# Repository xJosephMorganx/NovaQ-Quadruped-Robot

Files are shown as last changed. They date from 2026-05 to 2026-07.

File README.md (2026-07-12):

# NovaQ Quadruped Robot with Computer Vision

This repository documents and contains the files for a real quadruped robot built around an Arduino UNO Q. The project combines mechanical design, 3D printed parts, embedded motion control, a Python control layer, a web-based operator interface, and computer vision routines using OpenCV and Edge Impulse.

The robot has four legs with two degrees of freedom per leg. Eight MG996R servomotors are driven by a PCA9685 PWM controller, while the Arduino UNO Q separates high-level processing on its Linux side from low-level servo execution on its microcontroller side.

## Overview

The goal of the project is to build a functional robotics platform that can walk, turn, return to calibrated poses, show a greeting motion, stream camera video, track a blue ball, and respond to hand gestures.

```text
Web UI / ROG Ally
  -> Arduino App Lab on UNO Q Linux
  -> Python application
  -> Arduino Bridge
  -> UNO Q microcontroller sketch
  -> PCA9685 over I2C
  -> 8x MG996R servomotors
```

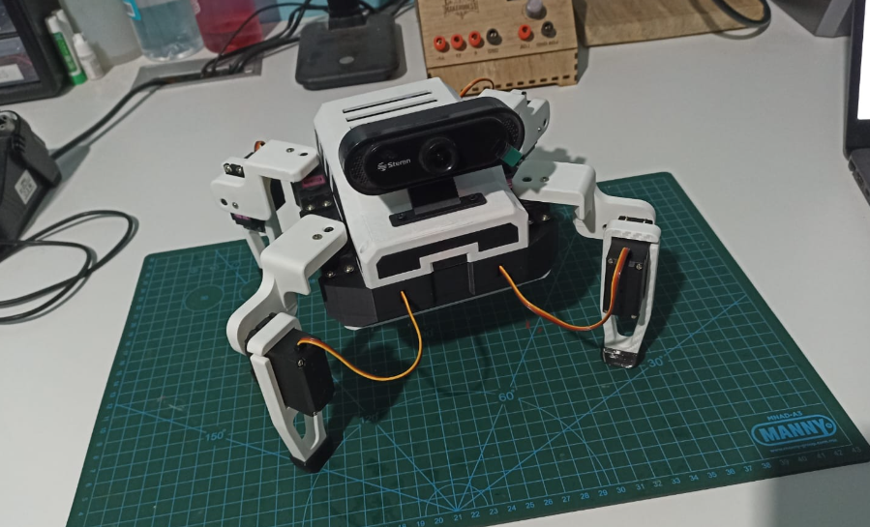
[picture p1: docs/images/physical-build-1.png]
Built quadruped robot


## Features

- Eight-servo quadruped platform with two degrees of freedom per leg.
- Manual Wi-Fi control through a browser-based web app.
- Live USB camera feedback for remote operation.
- OpenCV blue ball tracking mode.
- Edge Impulse hand gesture control mode.
- Motion routines for initial pose, stand, forward, backward, turns, and greeting.
- Smooth servo transitions using calibrated PCA9685 pulse values.
- 3D printed mechanical structure with printable STL files included in the repository.
- Separate power paths for logic and actuator stages.

## Mechanical Design

The mechanical structure was designed in Fusion 360 using the real dimensions of the main components: Arduino UNO Q, PCA9685 module, servomotors, battery, power bank, USB hub, camera, and internal wiring space. The design uses a central body, top case, base cover, camera mount, shoulders, legs, and feet.

Rigid parts were fabricated mainly in PLA. The feet were printed in TPU to improve floor contact and reduce slipping during gait tests. The repository includes STL files under `Design/STL/`, ready to slice and print.

The full mechanical design is also included for download and modification:

- `Design/Nova-Q.f3z`: editable Fusion 360 archive.
- `Design/Nova-Q.step`: neutral CAD export for other CAD tools.

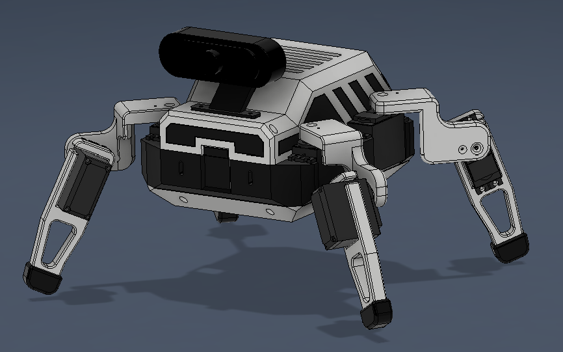
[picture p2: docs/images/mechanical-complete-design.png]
completed robot assembly in Fusion 360


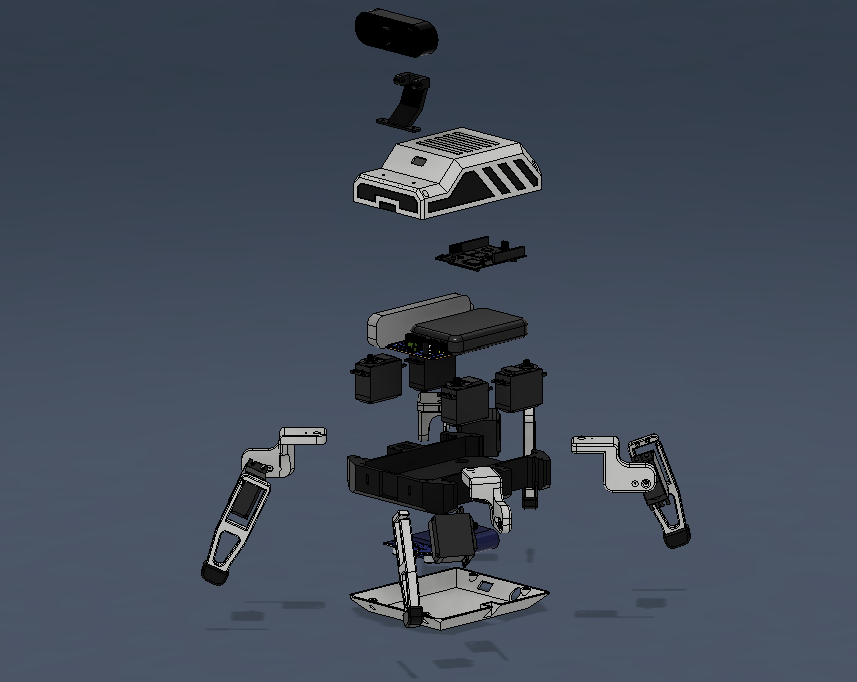
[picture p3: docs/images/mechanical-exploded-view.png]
Exploded robot assembly in Fusion 360


## Electrical and Electronic Design

The robot uses an Arduino UNO Q as the main controller and a PCA9685 module to generate PWM signals for the eight MG996R servomotors. The PCA9685 communicates with the UNO Q through I2C and drives channels `0-7`.

The power design separates logic and actuator supply. The servo stage is powered from a 12 V Li-ion battery through a buck converter adjusted for the MG996R operating voltage. The logic/peripheral stage uses a 5 V power bank. A common ground must be shared between the UNO Q, PCA9685, and servo power supply.

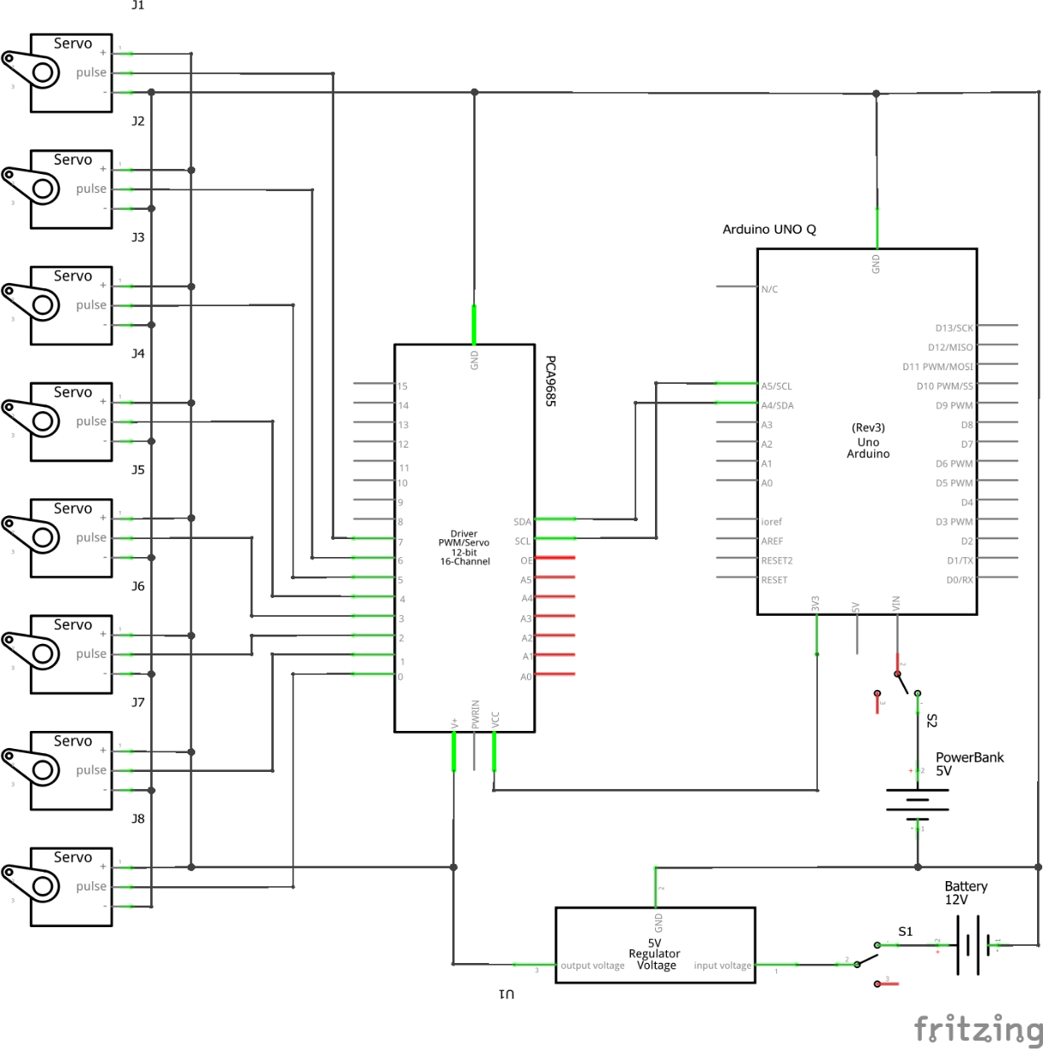
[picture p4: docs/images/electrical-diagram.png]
Electrical/electronic diagram


Important electrical notes:

- Do not power the MG996R servos directly from the UNO Q.
- Verify buck converter output before connecting the servos.
- Keep grounds common across control and power stages.
- Use wiring sized appropriately for the current demanded by the servos.
- Keep a physical power switch or battery disconnect available during testing.

## Bill of Materials

| Component | Type | Operating Voltage | Signal / Control | Purpose |
| --- | --- | --- | --- | --- |
| 8x MG996R servomotors | Actuator | 4.8-7.2 V | PWM | High-torque joints for legs |
| PCA9685 module | PWM controller | 3.3-5 V logic | I2C | 16-channel, 12-bit PWM generation |
| 12 V Li-ion battery | Power source | 12 V | Power | Main actuator supply |
| Buck converter | Regulator | 12 V input / adjustable output | DC-DC | Servo voltage regulation |
| ON/OFF switch | Switch | According to supply | Mechanical switching | Main power control |
| 5 V power bank | Auxiliary power source | 5 V | USB | Logic and peripheral supply |
| Arduino UNO Q | Control board | 5 V input / 3.3 V logic | Digital / I2C / Bridge | Main control and processing unit |
| Anker USB-C hub | USB hub | 5 V / USB-C PD | USB | Camera and peripheral connection |
| Steren COM-122 webcam | Visual sensor | 5 V USB | USB video | Camera input for live view and vision modes |
| 3D printed PLA parts | Mechanical structure | N/A | N/A | Body, cover, shoulders, legs, and camera mount |
| TPU feet | Contact parts | N/A | N/A | Traction and floor contact |

## Software

The software is split into two layers:

- **Microcontroller layer**: the Arduino sketch receives motion commands and executes calibrated servo routines through the PCA9685.
- **Linux/Python layer**: the Python app serves the web interface, handles camera capture, runs OpenCV logic, receives Edge Impulse results, and sends high-level commands through Arduino Bridge.

The repository also includes a dedicated servo calibration web app in `Dev/Tools/uno-q-servo-calibrator`. This tool is used to test individual servos and adjust pulse values before running the full quadruped motion routines.

Main software tools and libraries:

- Arduino App Lab
- Arduino Bridge / RPC
- `Wire.h`
- `Adafruit_PWMServoDriver.h`
- Python
- OpenCV
- Edge Impulse
- HTML, CSS, and JavaScript

## Web App

The web app is the main operator interface. It provides manual movement controls, keyboard input, touch input, connection state, last executed action, camera feedback, and access to the OpenCV and Edge Impulse modes.

## Desktop
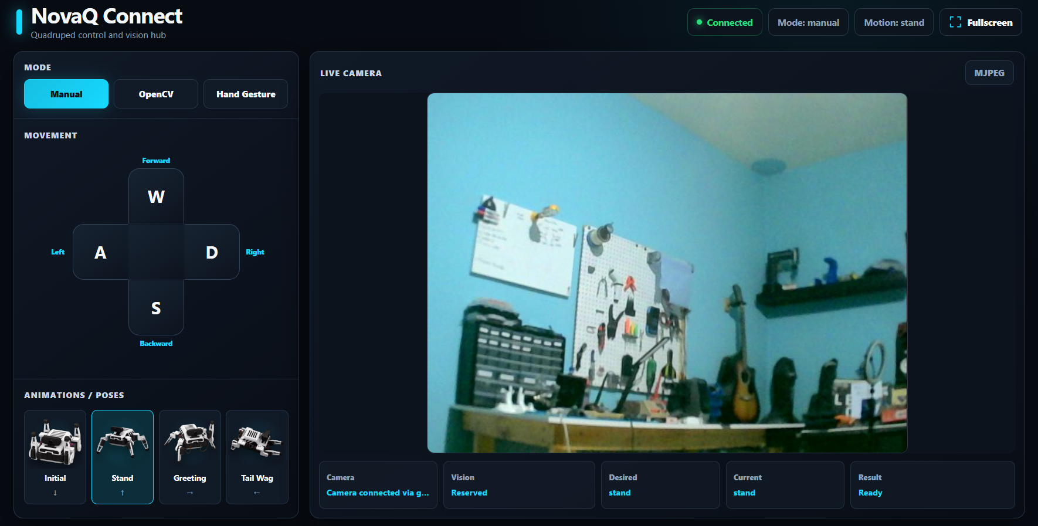
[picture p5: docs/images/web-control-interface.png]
Robot web control interface

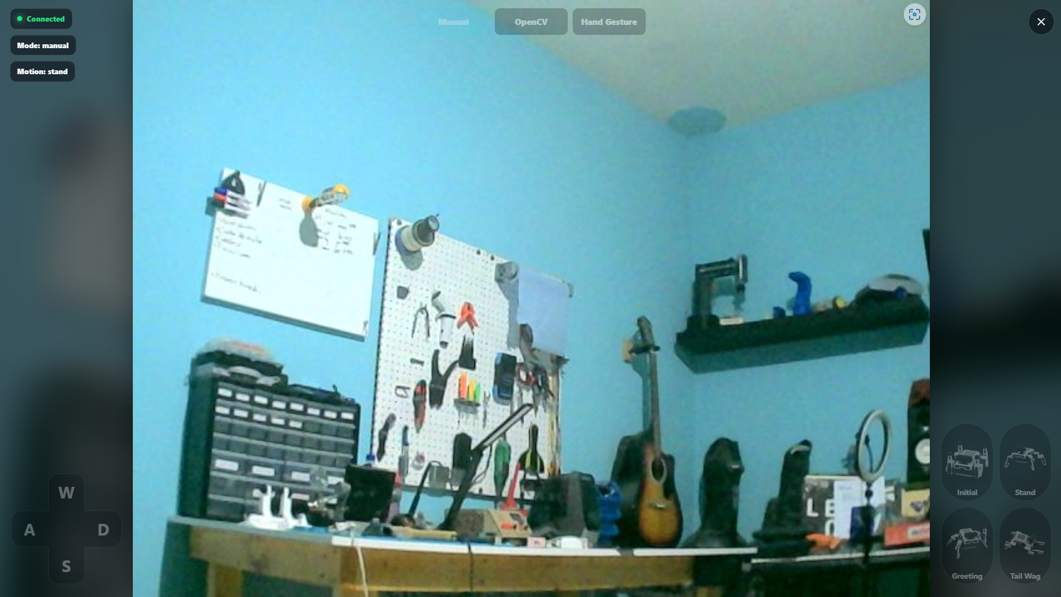
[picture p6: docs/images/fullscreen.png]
Robot web control interface fullscreen


## Mobile
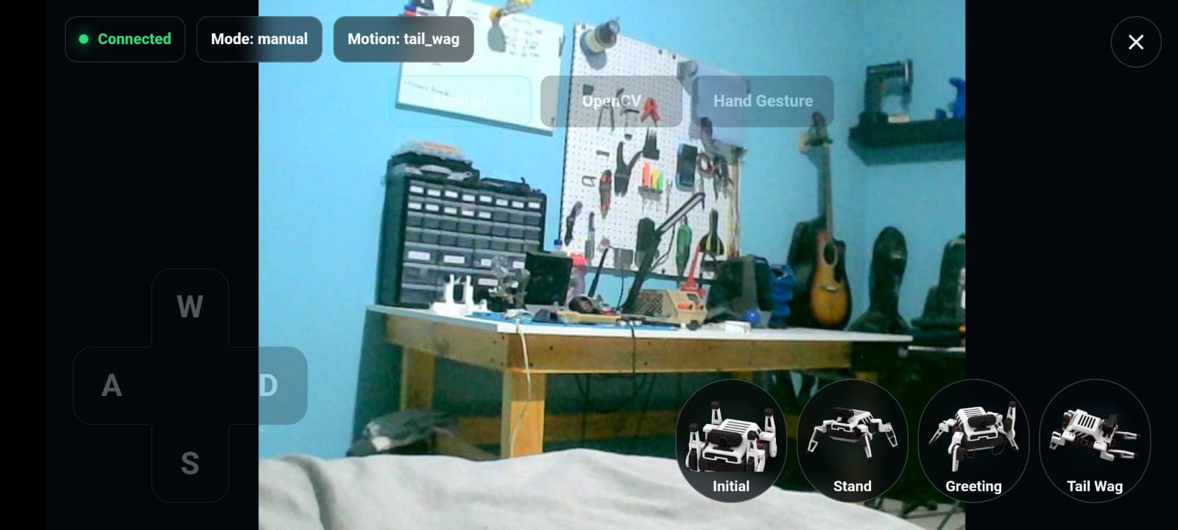
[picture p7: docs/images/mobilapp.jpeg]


Common controls:

| Input | Action |
| --- | --- |
| Arrow Down | Initial position |
| Arrow Up | Stand |
| W | Move forward |
| S | Move backward |
| A | Turn left |
| D | Turn right |
| Arrow Right | Greeting |
| Space | Manual mode |
| Page Down | OpenCV mode |
| F4 | Hand gesture mode |
| Escape | Focus/camera view |

## Computer Vision

The project includes two vision-based modes:

- **OpenCV mode**: detects a blue ball using color masking and shape filtering. The robot can search, correct its orientation, and move forward depending on the ball position.
- **Edge Impulse mode**: recognizes hand gestures and maps them to movement commands such as forward, backward, turn, stand, or greeting.

The camera is also used for live video feedback during manual operation.

## Installation

1. Clone the repository.

   ```bash
   git clone https://github.com/<user>/<repository>.git
   cd <repository>
   ```

2. Open the main Arduino App Lab project:

   ```text
   Dev/uno-q-control-station
   ```

3. Install or verify the sketch dependencies listed in:

   ```text
   Dev/uno-q-control-station/sketch/sketch.yaml
   ```

4. Install Python dependencies:

   ```bash
   pip install -r Dev/uno-q-control-station/python/requirements.txt
   ```

5. Calibrate the servos if needed using:

   ```text
   Dev/Tools/uno-q-servo-calibrator
   ```

6. Connect the UNO Q, PCA9685, servos, camera, power bank, battery, buck converter, and common ground.

7. Start the app from Arduino App Lab.

8. Open the control interface:

   ```text
   http://<UNO_Q_IP>:7000
   ```

## Usage

Before running gait routines, test the robot with the servo power disconnected and verify that the web app loads correctly. Then power the servos with the robot lifted off the table and test initial and stand positions first.

Recommended startup sequence:

1. Check wiring, polarity, and buck converter voltage.
2. Power the logic side and start the App Lab project.
3. Confirm the web app and camera feed work.
4. Connect servo power with the robot lifted.
5. Run `initial` and `stand`.
6. Test forward, backward, turn, and greeting routines.
7. Test OpenCV and Edge Impulse modes only after manual motion is stable.

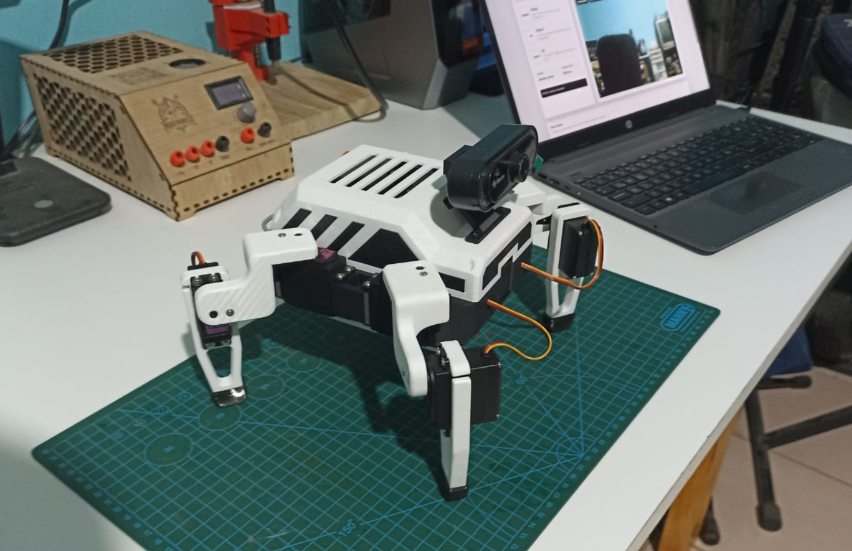
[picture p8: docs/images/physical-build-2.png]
Built quadruped robot alternate view


## Project Structure

```text
.
+-- Assets/
|   +-- Fusion_design.png
|   +-- NovaQ-schematic.png
|   +-- Physical1.png
|   +-- Physical2.png
|   +-- Nova_Q_exploded.mp4
+-- Design/
|   +-- Nova-Q.f3z
|   +-- Nova-Q.step
|   +-- STL/
|       +-- Base.stl
|       +-- Case.stl
|       +-- Camera_base.stl
|       +-- Leg*.stl
|       +-- Shoulder*.stl
|       +-- Foot*.stl
+-- Dev/
|   +-- uno-q-control-station/
|   |   +-- assets/
|   |   +-- python/
|   |   +-- sketch/
|   |   +-- app.yaml
|   +-- uno-q-keyboard-motion/
|   +-- Tools/
|       +-- uno-q-servo-calibrator/
+-- docs/
|   +-- images/
+-- README.md
```

## Notes

- The STL files in `Design/STL/` are included as printable mechanical parts. The editable Fusion 360 archive and STEP export are available in `Design/`.
- Servo pulse values depend on physical assembly and calibration. Recalibrate if servos, mounts, or linkages are changed.
- If additional external CAD files, trained models, or third-party assets are added later, their source and license should be documented in this README.
- The repository focuses on the complete robot implementation: electronics, firmware, Python software, web interface, mechanical integration, printable files, and documentation.

## License

This project is licensed under the GNU General Public License v3.0.

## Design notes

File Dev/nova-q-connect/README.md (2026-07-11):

# NovaQ Connect

Modern dark control and vision hub for the NovaQ quadruped. This app is an
independent UI-focused copy of `uno-q-control-station`; its Python bridge,
Arduino sketch, camera pipeline, vision modes, endpoints, motion sequencing,
and servo calibration remain unchanged.

## Controls

- Hold `W`, `S`, `A`, or `D` (keyboard or touch) to drive; release to return to
  `stand`.
- Arrow Down: `initial`
- Arrow Up: `stand`
- Arrow Right: `greeting`
- Arrow Left: `tail_wag`
- Space: `manual`
- PageDown: `opencv`
- F4: `hand_gesture`
- Escape: toggle Focus view

Focus view keeps the camera full-screen and presents low-opacity touch controls
for movement, poses, and app modes. Dashboard view shows only camera, vision,
desired motion, current motion, and the latest result.

## Services

- Web UI and API: port 7000
- Optional MJPEG stream: `http://<host>:7001/video-feed`
- API contracts are identical to `uno-q-control-station`.

Pose preview artwork is intentionally represented by CSS placeholders in the
first release and can later be replaced by pose-accurate photographic assets.

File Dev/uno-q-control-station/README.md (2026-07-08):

# UNO Q Control Station

Nueva app independiente para controlar el robot cuadrúpedo UNO Q sin reemplazar `uno-q-keyboard-motion`.

## Qué incluye

- Feed de cámara por snapshots en `/api/camera-frame`.
- Stream MJPEG en `http://<host>:7001/video-feed`.
- UI tipo focus view centrada en video con HUD.
- Modo Manual con teclado o controles tipo ROG Ally:
  - Arrow Down: `initial`
  - Arrow Up: `stand`
  - Arrow Right: `greeting`
  - W hold: `forward`
  - S hold: `backward`
  - A hold: `turn_left`
  - D hold: `turn_right`
  - Escape: focus/camera view
  - Space: `manual`
  - PageDown: `opencv`
  - F4: `hand_gesture`
- Modo OpenCV con tracking básico de pelota azul:
  - Máscara HSV azul.
  - Detector estricto por contorno circular: radio máximo, circularidad y densidad de relleno.
  - Si no detecta pelota: búsqueda con ráfaga de tres giros a la derecha.
  - Si detecta pelota fuera del centro: corrige con giro izquierdo/derecho.
  - Si detecta pelota centrada: avanza hacia adelante.
  - Si la pelota ya se ve grande/cerca: deja de mandar nuevos movimientos.
  - Entre movimientos espera 1.5 segundos sin mandar `stand`, para no revertir el avance o el giro recién hecho.
  - El feed muestra una vista anotada mientras OpenCV está activo.
- Modo Hand Gesture usando solo el brick `arduino:video_object_detection`:
  - Usa un modelo Edge Impulse en `/home/arduino/.arduino-bricks/ei-models/hand_gesture.eim`.
  - El brick detecta gestos de mano desnuda y entrega etiqueta, confianza y bounding box.
  - La app usa solo las cuatro etiquetas del modelo incluido:
    `five -> turn_right`, `good -> forward`, `neut -> backward`, `peace -> greeting`.
  - El mismo gesto se dispara una vez, con cooldown de 2.5 segundos, para evitar que un reconocimiento sostenido bloquee el control.
  - Las cajas anotadas expiran rapido para que el feed vuelva al video vivo si el brick deja de enviar detecciones.
  - Si no detecta mano o la etiqueta no esta mapeada: no manda movimiento.
  - La camara del brick usa `/dev/video0` directo y alimenta tambien el feed de la UI.
  - OpenCV queda reservado solo para el modo de pelota azul.
- Sketch con PCA9685 en `0x40`, canales `0-7`, `50 Hz`, reutilizando pulsos, poses y gait del prototipo.
  - `Shoulder_FR` calibrado en la app nueva con `initial=395`, `stand=330`; greeting usa `350` como soporte y fuerza retorno a `330`.

## Arquitectura de movimiento

La UI ya no encola un request por cada step mientras una tecla está presionada. Ahora publica cambios de estado con:

- `POST /api/mode` `{ "mode": "forward" }`
- `POST /api/mode` `{ "mode": "backward" }`
- `POST /api/mode` `{ "mode": "turn_left" }`
- `POST /api/mode` `{ "mode": "turn_right" }`
- `POST /api/mode` `{ "mode": "stand" }`
- `POST /api/mode` `{ "mode": "manual" }`
- `POST /api/mode` `{ "mode": "opencv" }`
- `POST /api/mode` `{ "mode": "hand_gesture" }`

`python/main.py` contiene `MotionController`, un worker único que serializa llamadas al Bridge, mantiene `desired_motion`, `current_motion` y `generation`, y descarta respuestas obsoletas. Si cambias rápido de `D` a `W`, la UI manda `turn_right` y luego `forward`; al soltar `D` no manda `stand` mientras `W` siga activo.

Los workers de vision no llaman al Bridge directamente. OpenCV lee el ultimo frame disponible; el brick de gestos recibe detecciones de Edge Impulse. Ambos publican el movimiento deseado en `MotionController`, para que los movimientos autonomos y manuales usen la misma cola serializada.

El sketch expone:

- `run_motion(motion)` para compatibilidad con el prototipo anterior.
- `run_mode_step(mode)` para la estación nueva.

Los steps siguen siendo bloqueantes dentro de Arduino mientras están ejecutando, pero Python deja de construir cola implícita y siempre toma el último modo deseado cuando el step actual termina.

## Endpoints principales

- `GET /api/state`
- `POST /api/mode`
- `GET /api/mode/<mode>`
- `GET /api/camera-frame`
- `GET http://<host>:7001/video-feed`

## Archivos

- `assets/index.html`: UI de control station.
- `assets/app.js`: estado de teclado, `set_mode`, camera refresh y HUD.
- `assets/styles.css`: layout responsive y focus view.
- `python/main.py`: cámara, MJPEG, MotionController y workers de visión.
- `sketch/sketch.ino`: movimientos, pulsos y Bridge functions.

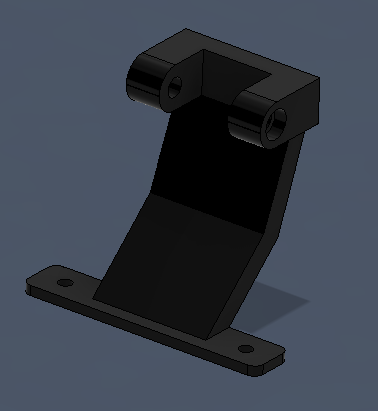
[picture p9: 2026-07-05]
docs/images/part-camera-base.png

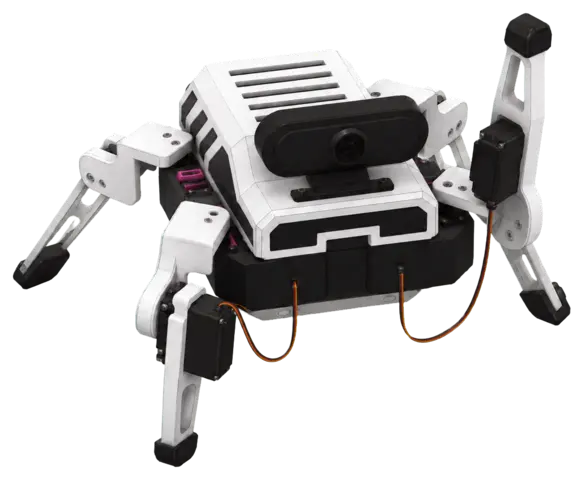
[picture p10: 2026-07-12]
Dev/nova-q-connect/assets/poses/greeting.webp

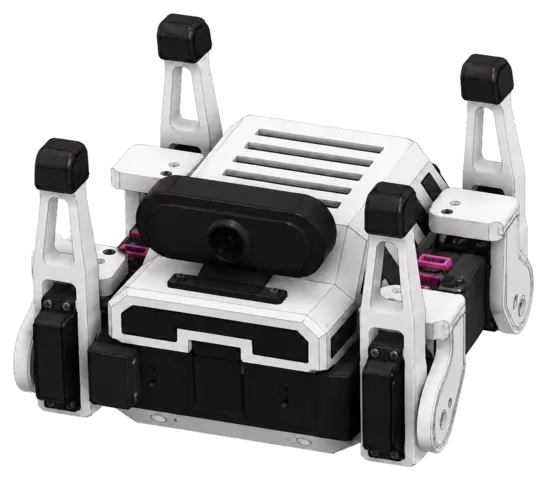
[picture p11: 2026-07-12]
Dev/nova-q-connect/assets/poses/initial.webp

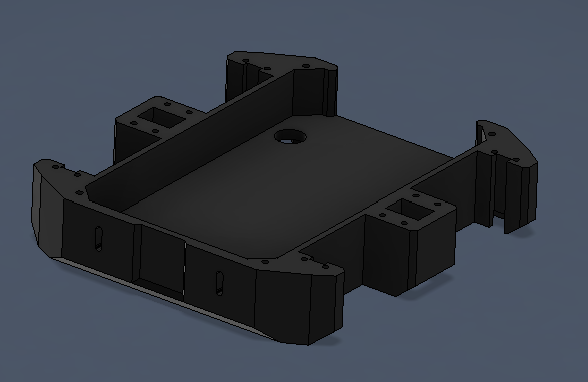
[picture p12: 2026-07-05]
docs/images/part-base.png

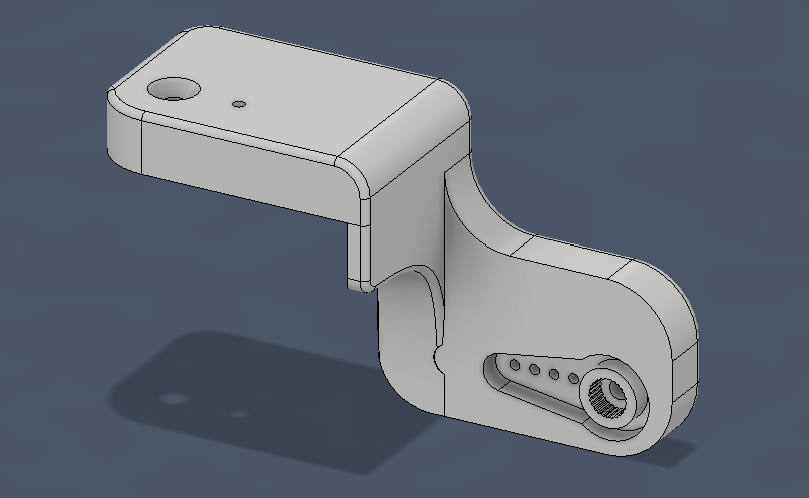
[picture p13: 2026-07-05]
docs/images/part-shoulder.png

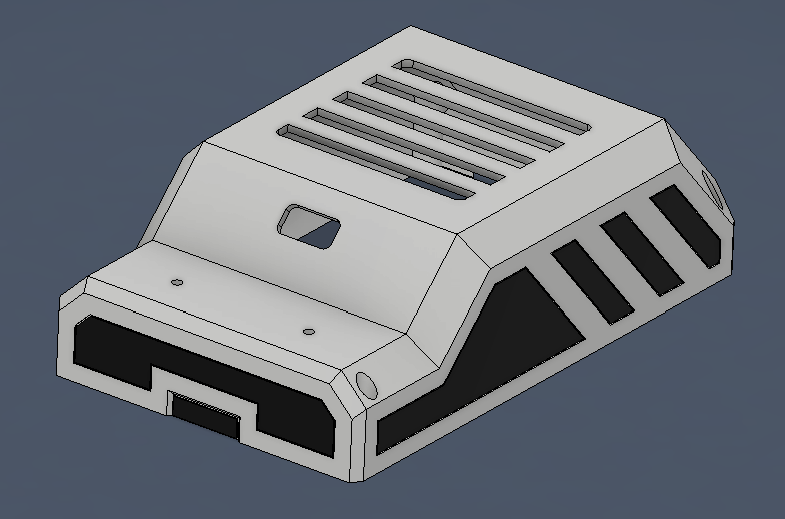
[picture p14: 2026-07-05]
docs/images/part-case.png

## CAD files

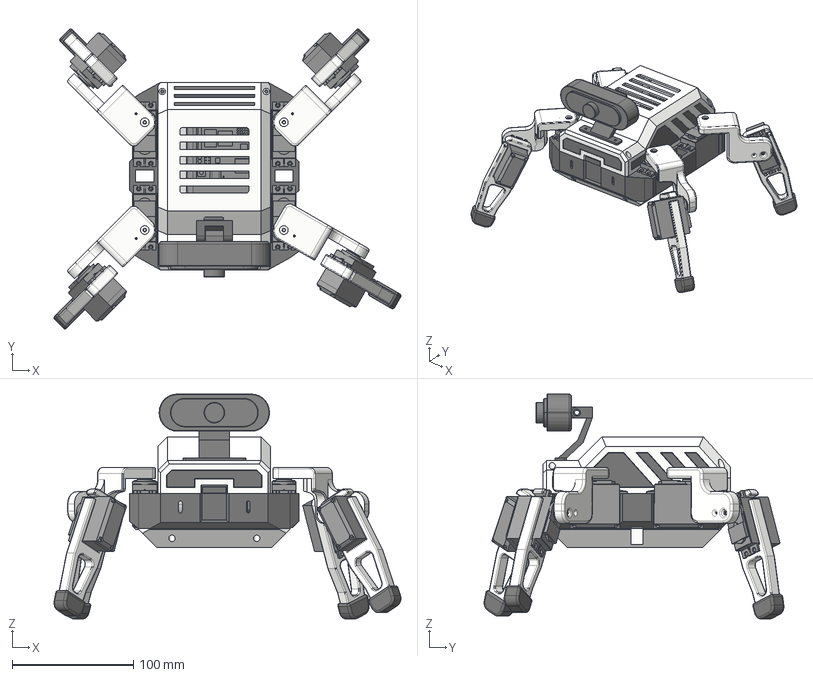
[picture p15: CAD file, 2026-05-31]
Design/Nova-Q.step
286.8 x 247.8 x 185.9 mm
MG996R_servo x 4
Document
Battery 12v
(Unsaved)
Hub
Power_bank
Camera
Base
Case
Base:cover
camera atachment v1
Servo Horns x 2
MG996R_servo_3 x 2
LegBR
Servo Horns_1 x 2
Servo Horns_2 x 2
Servo Horns_3 x 2
LegBR(Mirror) (4)
MG996R_servo_1
LegBR(Mirror) (4)(Mirror)
MG996R_servo_2
LegBR(Mirror) (4)(Mirror)(Mirror)

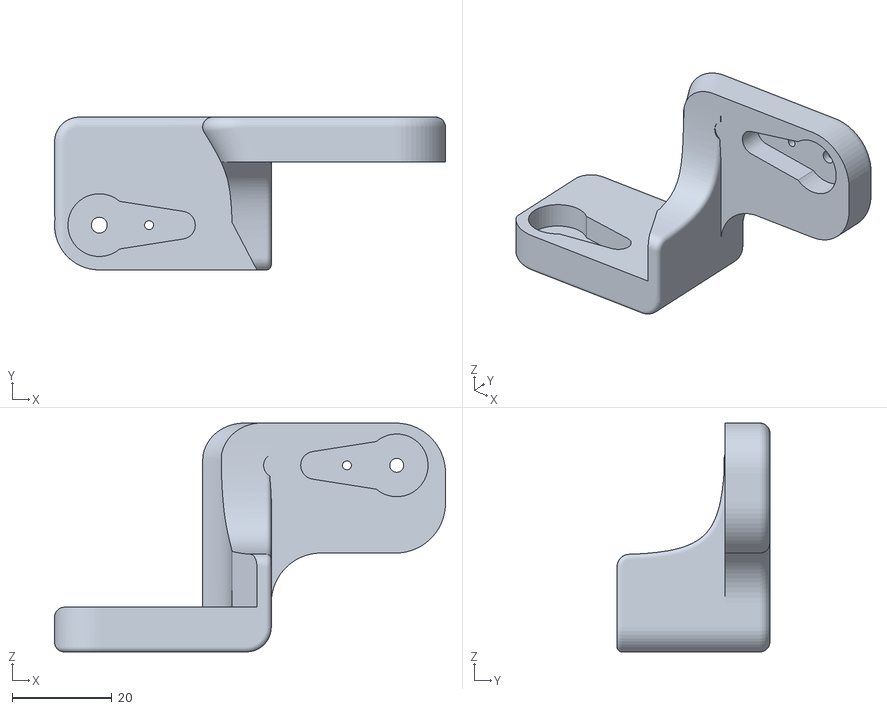
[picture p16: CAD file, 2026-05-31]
Design/STL/ShoulderBL.stl
78.6 x 30.7 x 46.0

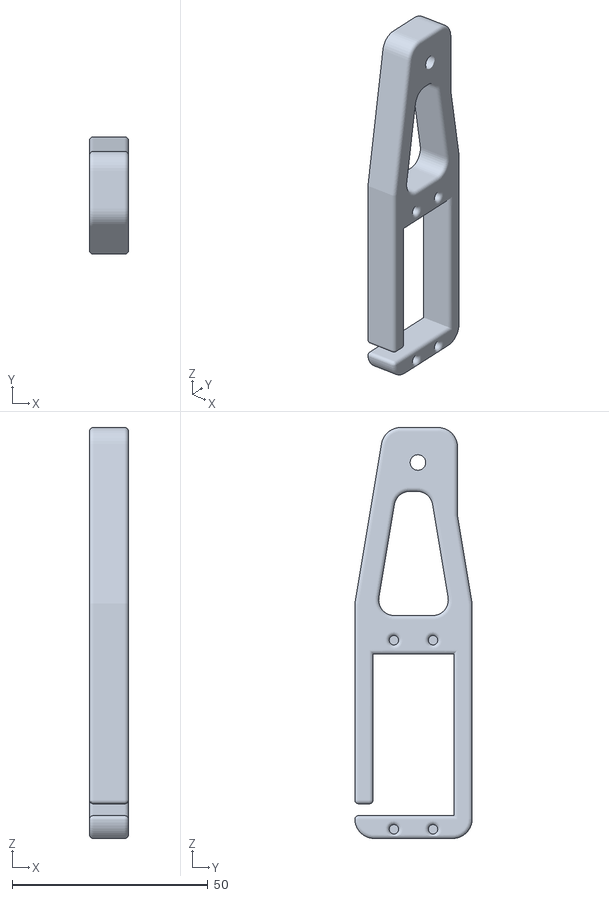
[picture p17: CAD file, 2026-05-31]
Design/STL/LegBL.stl
10.0 x 30.0 x 105.0

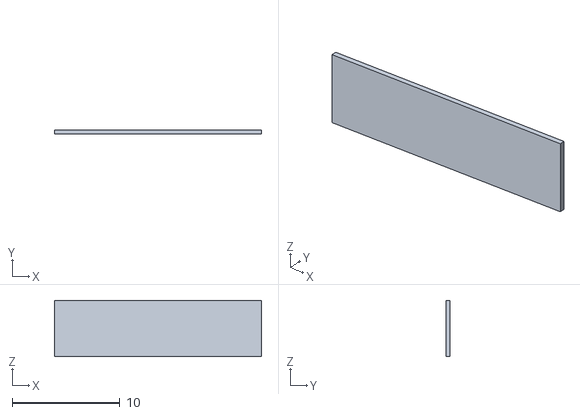
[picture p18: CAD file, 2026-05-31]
Design/STL/Dec_Front_2.stl
19.2 x 0.4 x 5.20

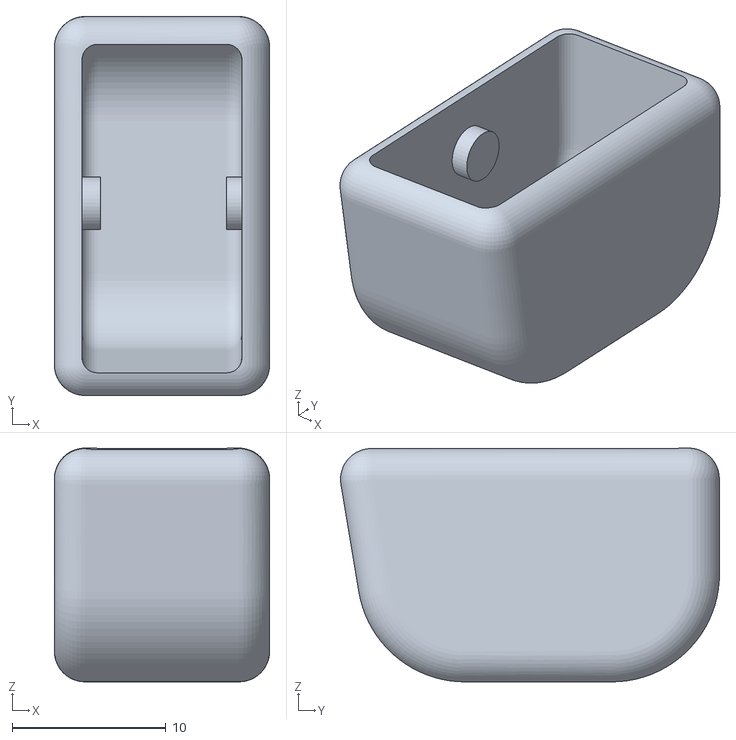
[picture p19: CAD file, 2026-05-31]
Design/STL/FootBR.stl
14.0 x 24.6 x 15.2

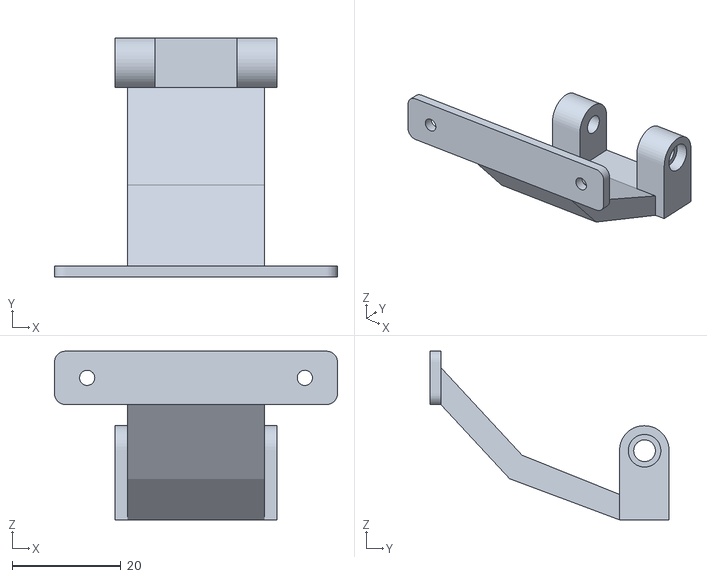
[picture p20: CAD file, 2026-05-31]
Design/STL/Camera_base.stl
52.0 x 43.9 x 31.0

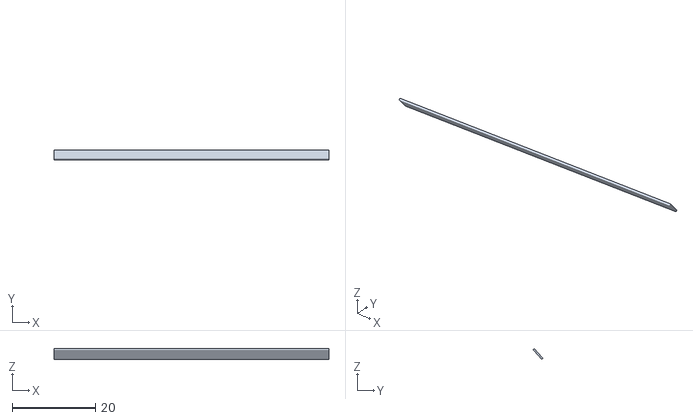
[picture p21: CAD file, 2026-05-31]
Design/STL/Dec_back_3.stl
66.2 x 2.35 x 2.56

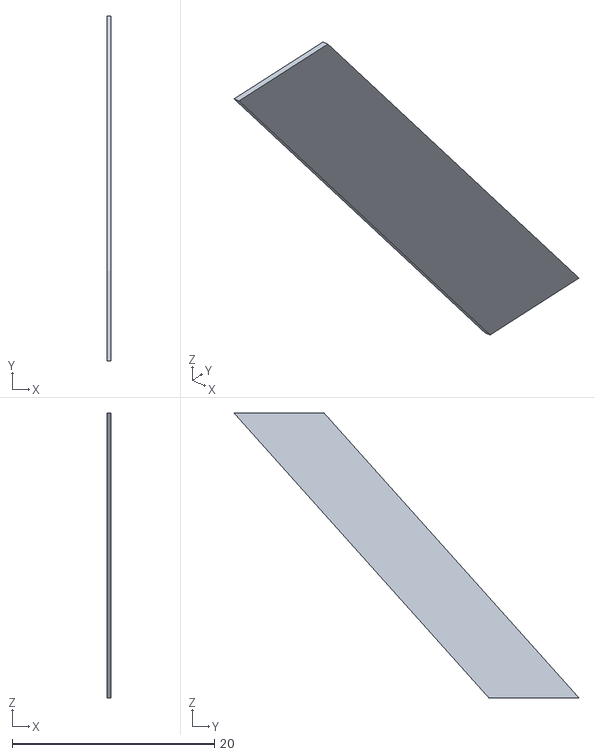
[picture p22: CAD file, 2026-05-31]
Design/STL/Dec_side_3.stl
0.4 x 34.2 x 28.2

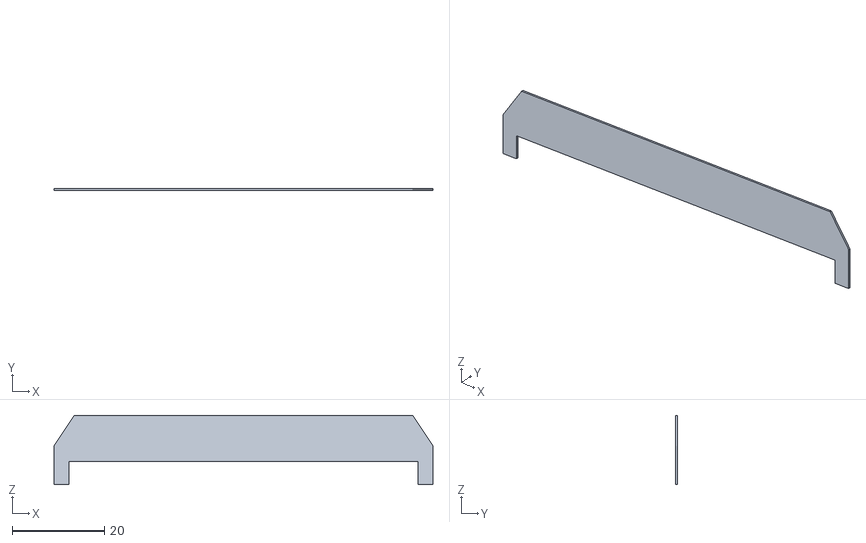
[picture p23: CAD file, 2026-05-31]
Design/STL/Dec_back_1.stl
82.2 x 0.4 x 15.1

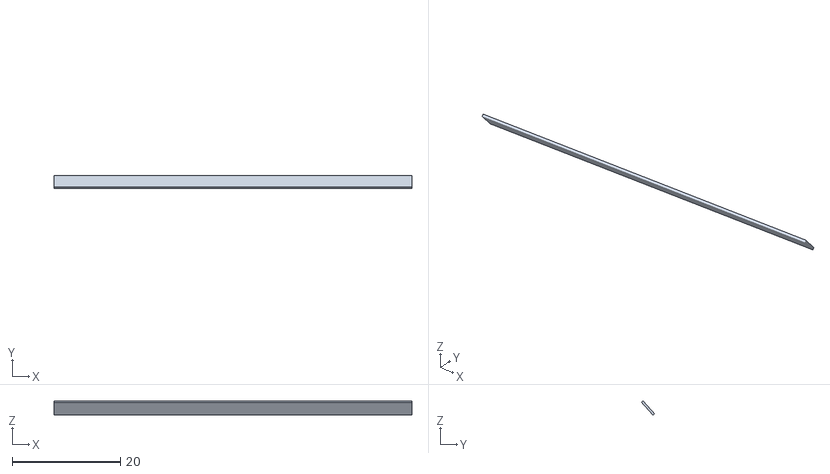
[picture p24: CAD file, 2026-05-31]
Design/STL/Dec_back_4.stl
66.2 x 2.42 x 2.63

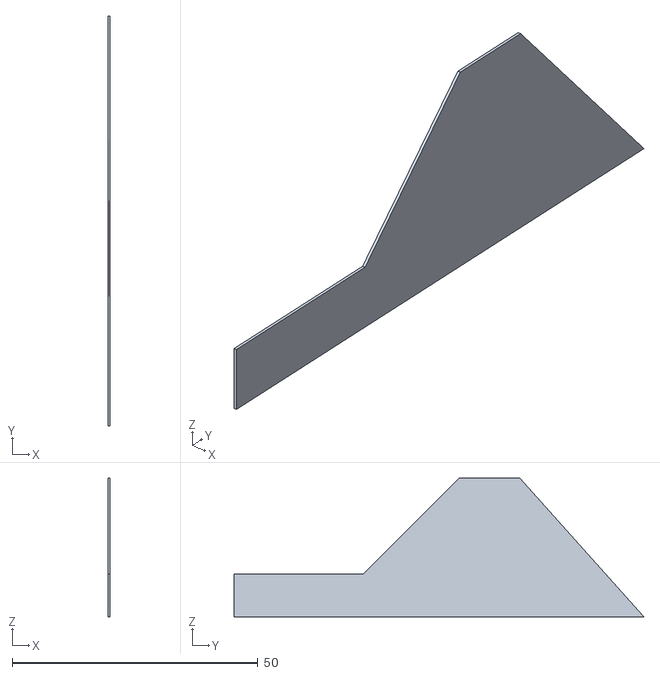
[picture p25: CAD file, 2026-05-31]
Design/STL/Dec_side_1.stl
0.4 x 83.3 x 28.2

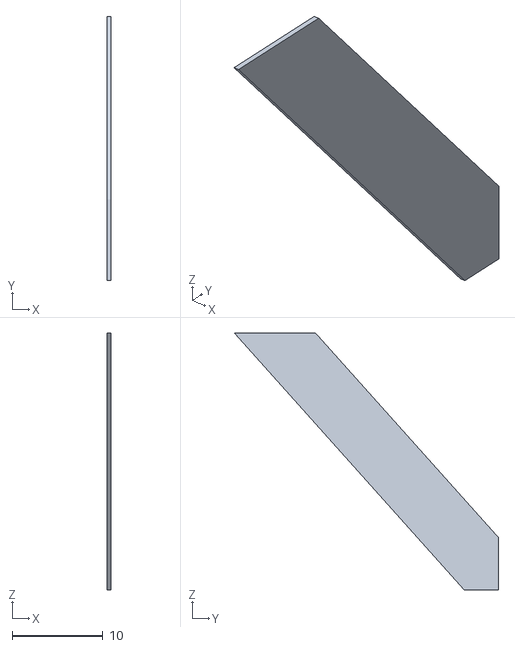
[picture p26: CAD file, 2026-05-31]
Design/STL/Dec_side_4.stl
0.4 x 29.0 x 28.2

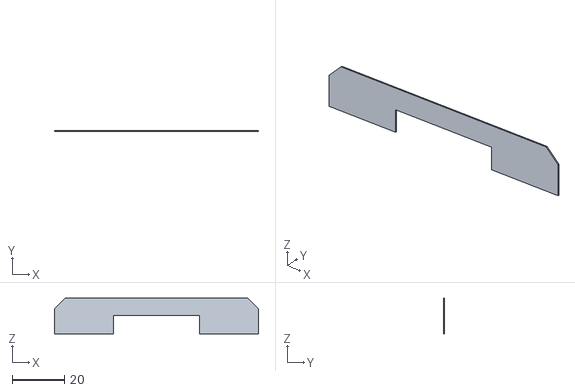
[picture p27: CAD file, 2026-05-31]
Design/STL/Dec_front_1.stl
78.2 x 0.4 x 13.7

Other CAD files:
Design/STL/FootBL.stl
Design/STL/FootFR.stl
Design/STL/LegFL.stl
Design/STL/ShoulderFL.stl
Design/Nova-Q.f3z
Design/STL/Base.stl
Design/STL/Base_cover.stl
Design/STL/Case.stl
Design/STL/Dec_back_2.stl
Design/STL/Dec_side_2.stl
Design/STL/LegBR.stl
Design/STL/ShoulderBR.stl

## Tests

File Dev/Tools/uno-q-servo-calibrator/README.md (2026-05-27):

# UNO Q Servo Calibrator

Web-based calibration tool for the quadruped robot servos using Arduino UNO Q,
Arduino App Lab, PCA9685, and MG996R servos.

## Overview

This app runs with the Arduino UNO Q split architecture:

```text
Browser over Wi-Fi
  -> Arduino App Lab WebUI on UNO Q Linux
  -> Python Bridge call
  -> UNO Q microcontroller sketch
  -> PCA9685 over I2C
  -> MG996R servos
```

The USB camera is read from the Linux side with OpenCV. Servo commands do not use
USB serial; they use the UNO Q Bridge API.

Servo calibration UI placeholder
Robot camera feed placeholder

## Project Structure

```text
uno-q-servo-calibrator/
+-- app.yaml
+-- assets/
|   +-- app.js
|   +-- index.html
|   +-- styles.css
+-- python/
|   +-- main.py
|   +-- requirements.txt
+-- sketch/
|   +-- sketch.ino
|   +-- sketch.yaml
+-- README.md
```

## Hardware

| Device | Connection |
| --- | --- |
| PCA9685 | UNO Q I2C bus |
| PCA9685 address | `0x40` |
| Servo signal channels | `0-7` |
| Servo power | External 6 V from buck converter |
| Camera | USB/UVC camera through USB hub |
| Common ground | UNO Q ground and servo power ground connected |

Do not power the MG996R servos from the UNO Q. Use the external 6 V servo supply.

## Default Servo Table

| Articulation | Channel | Pulse Min 0 deg | Pulse Max 180 deg |
| --- | ---: | ---: | ---: |
| Shoulder_FL | 0 | 70 | 495 |
| Leg_FL | 1 | 70 | 495 |
| Shoulder_FR | 2 | 70 | 500 |
| Leg_FR | 3 | 70 | 500 |
| Shoulder_BL | 4 | 70 | 500 |
| Leg_BL | 5 | 70 | 500 |
| Shoulder_BR | 6 | 70 | 495 |
| Leg_BR | 7 | 70 | 495 |

## Running in Arduino App Lab

1. Copy or import this folder into Arduino App Lab.
2. Install the sketch dependency `Adafruit PWM Servo Driver Library` if App Lab
   does not install it automatically.
3. Connect the UNO Q and the computer to the same Wi-Fi network.
4. Start the app from App Lab.
5. Open the WebUI at:

```text
http://<UNO_Q_IP>:7000
```

The optional MJPEG stream is available at:

```text
http://<UNO_Q_IP>:7001/video-feed
```

The UI also has a snapshot-based camera mode through WebUI, so calibration still
works if the extra MJPEG port is not exposed.

## Calibration Workflow

1. Select a PCA9685 channel from `0` to `7`.
2. Enter a pulse value or use the `-5`, `-1`, `+1`, and `+5` buttons.
3. Press `Send` or press `Enter` in the pulse input.
4. Watch the servo position and camera feed.
5. Press `Save` when the current working values are correct.
6. Use `Export JSON` to download the values from the browser.

The app does not move any servo automatically at startup. A servo only moves after
you send a command from the UI.

## Generated Calibration File

Saved values are written on the UNO Q Linux side to:

```text
python/calibration_values.json
```

This file is generated at runtime and can later be copied into the walking or
vision-control code as the robot's calibrated servo reference.

## Notes

- Safe pulse commands are clamped between `50` and `600`.
- The camera defaults to `/dev/video0`.
- If the camera is disconnected, the UI shows a camera unavailable state and the
  servo calibrator remains usable.
- Use App Lab Monitor logs instead of USB serial logs.

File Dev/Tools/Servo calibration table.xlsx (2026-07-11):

Calibracion de servos
 |  |  |  |  | Shoulders |  | arms
Articulacion | Canal | angulo_min | Angulo_max | punto medio | 0° | 90° | vertical_down | vertical_up
Shoulder_FL | 0 | 395 | 160 | 280 | 380 | 175
Leg_FL | 1 | 75 | 530 | 305 |  |  | 110 | 513
Shoulder_FR | 2 | 145 | 395 | 265 | 215 | 440
Leg_FR | 3 | 540 | 75 | 295 |  |  | 500 | 90
Shoulder_BL | 4 | 170 | 425 | 295 | 185 | 405
Leg_BL | 5 | 540 | 75 | 280 |  |  | 495 | 75
Shoulder_BR | 6 | 410 | 160 | 280 | 390 | 175
Leg_BR | 7 | 75 | 535 | 310 |  |  | 110 | 525
 |  |  |  |  | *shoulders 0° and 90° relative to the body
 |  |  |  |  | *arms verticaldown and upl relative to the floor

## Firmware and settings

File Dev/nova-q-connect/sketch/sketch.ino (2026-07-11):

#include <Arduino_RouterBridge.h>
#include <Wire.h>
#include <Adafruit_PWMServoDriver.h>

constexpr uint8_t Pca9685Address = 0x40;
constexpr uint8_t ServoFrequencyHz = 50;
constexpr uint8_t FirstServoChannel = 0;
constexpr uint8_t LastServoChannel = 7;
constexpr uint16_t SafePulseMin = 50;
constexpr uint16_t SafePulseMax = 600;
constexpr uint16_t SmoothStepPulse = 5;
constexpr uint16_t SmoothStepDelayMs = 15;
constexpr uint16_t InitialArmsStepDelayMs = 22;
constexpr uint16_t MotionStageDelayMs = 500;
constexpr uint16_t GreetingWavePauseMs = 120;
constexpr uint8_t GreetingWaveCycles = 3;
constexpr uint16_t TailWagPauseMs = 120;
constexpr uint8_t TailWagCycles = 4;
constexpr uint16_t GaitStepDelayMs = 5;
constexpr uint16_t GaitFramePauseMs = 20;

constexpr uint8_t ChannelShoulderFL = 0;
constexpr uint8_t ChannelLegFL = 1;
constexpr uint8_t ChannelShoulderFR = 2;
constexpr uint8_t ChannelLegFR = 3;
constexpr uint8_t ChannelShoulderBL = 4;
constexpr uint8_t ChannelLegBL = 5;
constexpr uint8_t ChannelShoulderBR = 6;
constexpr uint8_t ChannelLegBR = 7;

struct ServoTarget {
  uint8_t channel;
  uint16_t pulse;
};

//Initial

const ServoTarget InitialShoulders[] = {
  {ChannelShoulderFL, 175},
  {ChannelShoulderFR, 440},
  {ChannelShoulderBL, 405},
  {ChannelShoulderBR, 175},
};

const ServoTarget InitialLegs[] = {
  {ChannelLegFL, 513},
  {ChannelLegFR, 90},
  {ChannelLegBL, 75},
  {ChannelLegBR, 525},
};

//Stand

const ServoTarget StandShoulders[] = {
  {ChannelShoulderFL, 278},
  {ChannelShoulderFR, 328},
  {ChannelShoulderBL, 295},
  {ChannelShoulderBR, 283},
};

const ServoTarget StandLegs[] = {
  {ChannelLegFL, 110},
  {ChannelLegFR, 500},
  {ChannelLegBL, 495},
  {ChannelLegBR, 110},
};

//Greeting

const ServoTarget GreetingSupportLegs[] = {
  {ChannelLegFL, 430},
  {ChannelLegBR, 180},
};

const ServoTarget GreetingSupportShoulders[] = {
  {ChannelShoulderFR, 380},
};

const ServoTarget GreetingShoulderForward[] = {
  {ChannelShoulderFL, 235},
};

const ServoTarget GreetingShoulderBack[] = {
  {ChannelShoulderFL, 328},
};

const ServoTarget GreetingReturnFLToStand[] = {
  {ChannelLegFL, 110},
  {ChannelShoulderFL, 278},
};

const ServoTarget GreetingReturnBRToStand[] = {
  {ChannelLegBR, 110},
  {ChannelShoulderFR, 328},
};

//Tail Wag

const ServoTarget TailWagPose[] = {
  // Hombros delanteros en posición vertical.
  {ChannelShoulderFL, 175},
  {ChannelShoulderFR, 440},

  // Piernas delanteras aproximadamente a 90 grados.
  {ChannelLegFL, 312},
  {ChannelLegFR, 295},

  // Piernas traseras en posición de pie.
  {ChannelLegBL, 495},
  {ChannelLegBR, 110},
};

const ServoTarget TailWagSideA[] = {
  {ChannelShoulderBL, 240},
  {ChannelShoulderBR, 229},
};

const ServoTarget TailWagSideB[] = {
  {ChannelShoulderBL, 350},
  {ChannelShoulderBR, 336},
};

//Forward

const ServoTarget ForwardPrepare[] = {
  {ChannelLegFL, 110},
  {ChannelLegFR, 500},
  {ChannelLegBL, 495},
  {ChannelLegBR, 110},
};

const ServoTarget ForwardLiftA[] = {
  {ChannelLegFL, 200},
  {ChannelLegBR, 200},
};

const ServoTarget ForwardPlaceA[] = {
  {ChannelShoulderFL, 226},
  {ChannelShoulderBR, 336},
};

const ServoTarget ForwardPlantA[] = {
  {ChannelLegFL, 110},
  {ChannelLegBR, 110},
};

const ServoTarget ForwardPushA[] = {
  {ChannelShoulderFL, 329},
  {ChannelShoulderBR, 229},
};

const ServoTarget ForwardLiftB[] = {
  {ChannelLegFR, 410},
  {ChannelLegBL, 410},
};

const ServoTarget ForwardPlaceB[] = {
  {ChannelShoulderFR, 384},
  {ChannelShoulderBL, 240},
};

const ServoTarget ForwardPlantB[] = {
  {ChannelLegFR, 500},
  {ChannelLegBL, 495},
};

const ServoTarget ForwardPushB[] = {
  {ChannelShoulderFR, 271},
  {ChannelShoulderBL, 350},
};

//Backward

const ServoTarget BackwardPlaceA[] = {
  {ChannelShoulderFL, 329},
  {ChannelShoulderBR, 229},
};

const ServoTarget BackwardPushA[] = {
  {ChannelShoulderFL, 226},
  {ChannelShoulderBR, 336},
};

const ServoTarget BackwardPlaceB[] = {
  {ChannelShoulderFR, 271},
  {ChannelShoulderBL, 350},
};

const ServoTarget BackwardPushB[] = {
  {ChannelShoulderFR, 384},
  {ChannelShoulderBL, 240},
};

//Left

const ServoTarget TurnLeftPlaceA[] = {
  {ChannelShoulderFL, 329},
  {ChannelShoulderBR, 336},
};

const ServoTarget TurnLeftPushA[] = {
  {ChannelShoulderFL, 226},
  {ChannelShoulderBR, 229},
};

const ServoTarget TurnLeftPlaceB[] = {
  {ChannelShoulderFR, 384},
  {ChannelShoulderBL, 350},
};

const ServoTarget TurnLeftPushB[] = {
  {ChannelShoulderFR, 271},
  {ChannelShoulderBL, 240},
};

//Right

const ServoTarget TurnRightPlaceA[] = {
  {ChannelShoulderFL, 226},
  {ChannelShoulderBR, 229},
};

const ServoTarget TurnRightPushA[] = {
  {ChannelShoulderFL, 329},
  {ChannelShoulderBR, 336},
};

const ServoTarget TurnRightPlaceB[] = {
  {ChannelShoulderFR, 271},
  {ChannelShoulderBL, 240},
};

const ServoTarget TurnRightPushB[] = {
  {ChannelShoulderFR, 384},
  {ChannelShoulderBL, 350},
};

//

Adafruit_PWMServoDriver pwm = Adafruit_PWMServoDriver(Pca9685Address);
uint16_t currentPulses[LastServoChannel + 1] = {300, 300, 300, 300, 300, 300, 300, 300};

uint16_t clampPulse(int pulse) {
  if (pulse < SafePulseMin) {
    return SafePulseMin;
  }
  if (pulse > SafePulseMax) {
    return SafePulseMax;
  }
  return static_cast<uint16_t>(pulse);
}

void writeServoPulse(uint8_t channel, uint16_t pulse) {
  uint16_t safePulse = clampPulse(pulse);
  pwm.setPWM(channel, 0, safePulse);
  currentPulses[channel] = safePulse;
}

uint16_t stepPulseToward(uint16_t currentPulse, uint16_t targetPulse) {
  if (currentPulse < targetPulse) {
    uint16_t nextPulse = currentPulse + SmoothStepPulse;
    return nextPulse > targetPulse ? targetPulse : nextPulse;
  }

  int nextPulse = static_cast<int>(currentPulse) - SmoothStepPulse;
  return nextPulse < targetPulse ? targetPulse : static_cast<uint16_t>(nextPulse);
}

void moveTargetsSmooth(const ServoTarget targets[], size_t targetCount, uint16_t stepDelayMs = SmoothStepDelayMs) {
  bool allAtTarget = false;

  while (!allAtTarget) {
    allAtTarget = true;

    for (size_t index = 0; index < targetCount; index++) {
      uint8_t channel = targets[index].channel;
      uint16_t safeTarget = clampPulse(targets[index].pulse);
      uint16_t currentPulse = currentPulses[channel];

      if (currentPulse != safeTarget) {
        writeServoPulse(channel, stepPulseToward(currentPulse, safeTarget));
        allAtTarget = false;
      }
    }

    if (!allAtTarget) {
      delay(stepDelayMs);
    }
  }
}

String setServoPulse(int channel, int pulse) {
  if (channel < FirstServoChannel || channel > LastServoChannel) {
    return "error: invalid channel";
  }

  writeServoPulse(static_cast<uint8_t>(channel), clampPulse(pulse));
  return "ok";
}

void moveInitial() {
  moveTargetsSmooth(InitialLegs, sizeof(InitialLegs) / sizeof(InitialLegs[0]), InitialArmsStepDelayMs);
  delay(MotionStageDelayMs);
  moveTargetsSmooth(InitialShoulders, sizeof(InitialShoulders) / sizeof(InitialShoulders[0]));
}

void moveStand() {
  moveTargetsSmooth(StandShoulders, sizeof(StandShoulders) / sizeof(StandShoulders[0]));
  delay(MotionStageDelayMs);
  moveTargetsSmooth(StandLegs, sizeof(StandLegs) / sizeof(StandLegs[0]));
}

void moveGreeting() {
  moveStand();
  delay(MotionStageDelayMs);
  moveTargetsSmooth(GreetingSupportShoulders, sizeof(GreetingSupportShoulders) / sizeof(GreetingSupportShoulders[0]));
  delay(MotionStageDelayMs);
  moveTargetsSmooth(GreetingSupportLegs, sizeof(GreetingSupportLegs) / sizeof(GreetingSupportLegs[0]));
  delay(MotionStageDelayMs);

  for (uint8_t cycle = 0; cycle < GreetingWaveCycles; cycle++) {
    moveTargetsSmooth(GreetingShoulderForward, sizeof(GreetingShoulderForward) / sizeof(GreetingShoulderForward[0]));
    delay(GreetingWavePauseMs);
    moveTargetsSmooth(GreetingShoulderBack, sizeof(GreetingShoulderBack) / sizeof(GreetingShoulderBack[0]));
    delay(GreetingWavePauseMs);
  }

  moveTargetsSmooth(GreetingReturnFLToStand, sizeof(GreetingReturnFLToStand) / sizeof(GreetingReturnFLToStand[0]));
  delay(MotionStageDelayMs);
  moveTargetsSmooth(GreetingReturnBRToStand, sizeof(GreetingReturnBRToStand) / sizeof(GreetingReturnBRToStand[0]));
}

void moveTailWag() {
  // Comienza desde una posición estable.
  moveStand();
  delay(MotionStageDelayMs);

  // Coloca la parte delantera y las piernas traseras.
  moveTargetsSmooth(
    TailWagPose,
    sizeof(TailWagPose) / sizeof(TailWagPose[0])
  );
  delay(MotionStageDelayMs);

  // Mueve los hombros traseros de lado a lado.
  for (uint8_t cycle = 0; cycle < TailWagCycles; cycle++) {
    moveTargetsSmooth(
      TailWagSideA,
      sizeof(TailWagSideA) / sizeof(TailWagSideA[0])
    );
    delay(TailWagPauseMs);

    moveTargetsSmooth(
      TailWagSideB,
      sizeof(TailWagSideB) / sizeof(TailWagSideB[0])
    );
    delay(TailWagPauseMs);
  }

  // Regresa a la posición de pie.
  moveStand();
}

void moveGaitStep(
  const ServoTarget placeA[],
  const ServoTarget pushA[],
  const ServoTarget placeB[],
  const ServoTarget pushB[]
) {
  moveTargetsSmooth(ForwardPrepare, sizeof(ForwardPrepare) / sizeof(ForwardPrepare[0]), GaitStepDelayMs);
  delay(GaitFramePauseMs);

  moveTargetsSmooth(ForwardLiftA, sizeof(ForwardLiftA) / sizeof(ForwardLiftA[0]), GaitStepDelayMs);
  delay(GaitFramePauseMs);
  moveTargetsSmooth(placeA, 2, GaitStepDelayMs);
  delay(GaitFramePauseMs);
  moveTargetsSmooth(ForwardPlantA, sizeof(ForwardPlantA) / sizeof(ForwardPlantA[0]), GaitStepDelayMs);
  delay(GaitFramePauseMs);
  moveTargetsSmooth(pushA, 2, GaitStepDelayMs);
  delay(GaitFramePauseMs);

  moveTargetsSmooth(ForwardLiftB, sizeof(ForwardLiftB) / sizeof(ForwardLiftB[0]), GaitStepDelayMs);
  delay(GaitFramePauseMs);
  moveTargetsSmooth(placeB, 2, GaitStepDelayMs);
  delay(GaitFramePauseMs);
  moveTargetsSmooth(ForwardPlantB, sizeof(ForwardPlantB) / sizeof(ForwardPlantB[0]), GaitStepDelayMs);
  delay(GaitFramePauseMs);
  moveTargetsSmooth(pushB, 2, GaitStepDelayMs);
  delay(GaitFramePauseMs);
}

void moveForwardStep() {
  moveGaitStep(ForwardPlaceA, ForwardPushA, ForwardPlaceB, ForwardPushB);
}

void moveBackwardStep() {
  moveGaitStep(BackwardPlaceA, BackwardPushA, BackwardPlaceB, BackwardPushB);
}

void moveTurnLeftStep() {
  moveGaitStep(TurnLeftPlaceA, TurnLeftPushA, TurnLeftPlaceB, TurnLeftPushB);
}

void moveTurnRightStep() {
  moveGaitStep(TurnRightPlaceA, TurnRightPushA, TurnRightPlaceB, TurnRightPushB);
}

String runMotion(String motionName) {
  motionName.trim();
  motionName.toLowerCase();

  if (motionName == "initial") {
    moveInitial();
    return "ok: initial";
  }

  if (motionName == "stand") {
    moveStand();
    return "ok: stand";
  }

  if (motionName == "greeting") {
    moveGreeting();
    return "ok: greeting";
  }

  if (motionName == "tail_wag") {
    moveTailWag();
    return "ok: tail_wag";
  }

  if (motionName == "forward_step") {
    moveForwardStep();
    return "ok: forward_step";
  }

  if (motionName == "backward_step") {
    moveBackwardStep();
    return "ok: backward_step";
  }

  if (motionName == "turn_left_step") {
    moveTurnLeftStep();
    return "ok: turn_left_step";
  }

  if (motionName == "turn_right_step") {
    moveTurnRightStep();
    return "ok: turn_right_step";
  }

  return "error: unknown motion";
}

String runModeStep(String modeName) {
  modeName.trim();
  modeName.toLowerCase();
  modeName.replace("-", "_");

  if (modeName == "initial") {
    moveInitial();
    return "ok: initial";
  }

  if (modeName == "stand") {
    moveStand();
    return "ok: stand";
  }

  if (modeName == "greeting") {
    moveGreeting();
    return "ok: greeting";
  }

  if (modeName == "tail_wag") {
    moveTailWag();
    return "ok: tail_wag";
  }

  if (modeName == "forward") {
    moveForwardStep();
    return "ok: forward";
  }

  if (modeName == "backward") {
    moveBackwardStep();
    return "ok: backward";
  }

  if (modeName == "turn_left") {
    moveTurnLeftStep();
    return "ok: turn_left";
  }

  if (modeName == "turn_right") {
    moveTurnRightStep();
    return "ok: turn_right";
  }

  return "error: unknown mode";
}

void setup() {
  Bridge.begin();
  Monitor.begin();

  Wire.begin();
  pwm.begin();
  pwm.setPWMFreq(ServoFrequencyHz);
  delay(10);

  Bridge.provide_safe("set_servo_pulse", setServoPulse);
  Bridge.provide_safe("run_motion", runMotion);
  Bridge.provide_safe("run_mode_step", runModeStep);

  Monitor.println("UNO Q control station ready");
}

void loop() {
}

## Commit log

2026-05-27 Initial robot workspace checkpoint
    [ArmBL.3mf, ArmBR.3mf, ArmFL.3mf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]
2026-05-27 Update keyboard motion calibration values
2026-05-31 Prepare project for GitHub upload
    [ArmBL.3mf, ArmBR.3mf, ArmFL.3mf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]
2026-05-31 Update keyboard motion servo calibration
2026-06-01 Implement control mode architecture
    [Servo calibration table.xlsx]
2026-06-01 Tune OpenCV tracking filters
2026-06-01 Checkpoint before hand gesture camera fix
2026-06-01 Fix hand gesture camera fallback
2026-06-01 Prevent stale gesture camera frames
2026-06-10 Fix Shoulder FR stand calibration
    [sketch.ino]
2026-07-11 Add tail wag UI button and tune motion
2026-07-11 Reorganize NovaQ connect project
    [Servo calibration table.xlsx]
